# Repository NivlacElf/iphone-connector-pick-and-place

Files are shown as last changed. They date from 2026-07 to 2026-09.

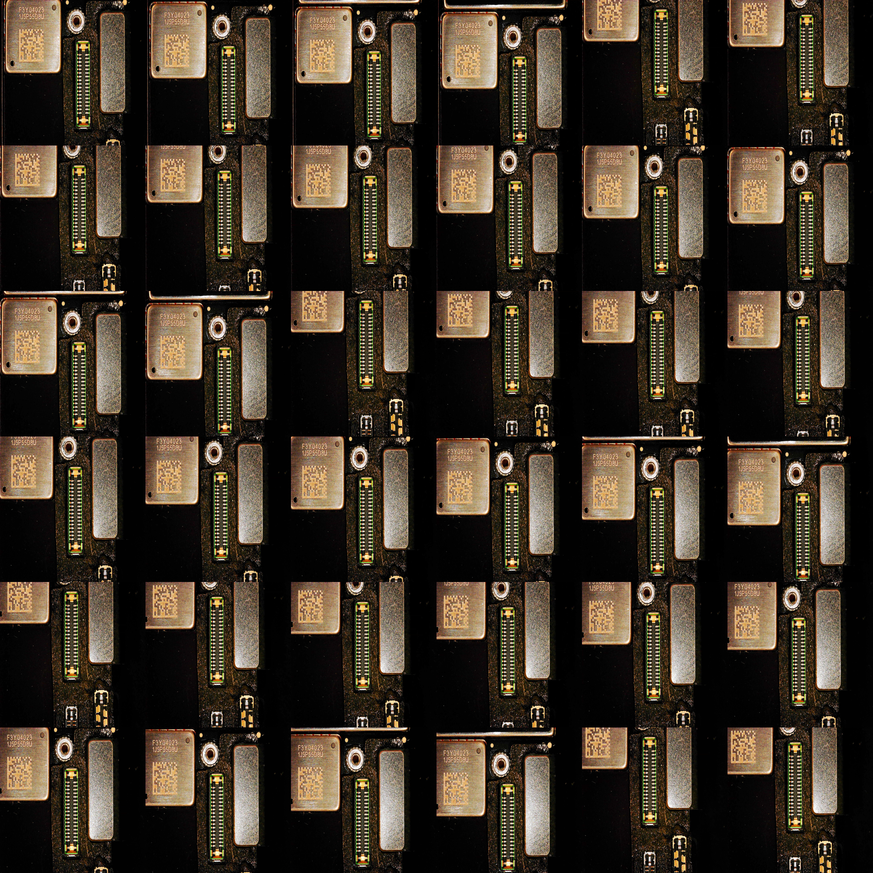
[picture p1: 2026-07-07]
experiments/Socket Sam/grid/socket_grid_6x6.png

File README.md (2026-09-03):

# Autonomous iPhone Connector Pick-and-Place

A machine that picks up an Apple iPhone flex-cable plug and inserts it into its board socket. It's built from a modified Ender 3 3D printer, two cameras, and three custom-trained YOLOv8 vision models.

Connector mating is one of the last steps in phone assembly still done by human hands: the plug is a few millimeters wide and the socket tolerance is fractions of a millimeter. This project closes that gap with visual servoing instead of expensive precision robotics.

<!-- IMAGE: hero shot of the full rig (Ender 3 + toolhead + phone case holder), ~1200px wide -->
Full rig

**[▶ Watch the full demo video](YOUTUBE_LINK_HERE)**

## How It Works

The Ender 3 is used as a cheap, precise 3-axis CNC motion platform, driven over USB with G-code. Two cameras give the machine eyes:

| Camera | Direction | Job |
|---|---|---|
| Toolhead camera | Looking down | Finds the plug on the table, then finds the socket on the phone |
| Microscope | Looking up | Inspects the plug held by the picker to measure its exact offset and angle |

Three YOLOv8 oriented-bounding-box models handle detection: `plug_front.pt` (plug on the table), `plug_back.pt` (pin side of the plug, viewed from below), and `SocketML.pt` (board socket). (see google drive models foulder for the models. The file is too big for github)

Each process uses the same pattern: detect the target, convert its pixel offset from image center to millimeters (calibrated per Z height), move the printer, and re-detect — repeating until the error converges to near zero.

### The Pipeline

<!-- IMAGE: 4-panel strip showing phases 1, 3, 4, 5 (annotated camera views), or one diagram -->
Pipeline phases

1. **Find the plug** — the downward camera servos over the plug, then applies the calibrated camera-to-picker offset so the picker lands exactly on the grab point.
2. **Pick up** — the toolhead descends and the pneumatic vacuum gripper grabs the plug.
3. **Square the plug** — the plug is pressed against a straight edge to zero out its rotation.
4. **Inspect from below** — the machine holds the plug over the upward microscope, verifies the squaring worked (angle check), and measures precisely where the plug sits on the picker. This shift is carried into the final math, so a slightly off-center grab still ends in a perfect insertion.
5. **Find the socket** — the downward camera servos over the board socket on the phone.
6. **Insert** — the true target is computed as `socket position + nominal offset − measured grab shift`, and a slow stepped descent seats the plug into the socket.

## Hardware

<!-- IMAGE: close-up of the custom toolhead attachment + picker -->
Toolhead and picker

<!-- IMAGE: phone case holder with iPhone board in place -->
Phone holder

- Creality Ender 3 3D printer (motion platform, stock firmware, G-code over serial)
- [Pneumatic vacuum gripper for electronics (McMaster-Carr 5083N126)](https://www.mcmaster.com/5083N126/) to pick up the plug
- Custom 3D-printed toolhead camera/gripper mount
- Custom 3D-printed camera base mount
- Custom 3D-printed iPhone holder to fixture the phone
- Downward-facing toolhead camera (1600×1200)
- Upward-facing USB microscope
- Straight-edge fixture for squaring the plug

All custom parts were designed in CAD — STEP files are in [`cad/`](cad/), ready to print.

## Machine Learning

The three models were trained on images captured by the machine itself: a grid-sweep script (`training/Picture_Grid.py`) moves the camera over the workspace and photographs the target at known coordinates, giving hundreds of labeled-position images per session. Labels were drawn as oriented rectangles/parallelograms, propagated across the sweep, and converted from CSV to YOLO OBB format (`scripts/csvToYolo.py`, `scripts/yolo_to_obb.py`).

<!-- IMAGE: example detection — camera frame with OBB drawn on the plug or socket -->
YOLO detection example

Oriented bounding boxes (rather than axis-aligned ones) matter here: the plug's rotation is part of the measurement, and the OBB angle feeds directly into the squaring verification.

## Repository Structure

```
├── src/                  # Final pipeline
│   ├── alignment.py      #   Full pick-and-place workflow (run this)
│   ├── Calibrate.py      #   Offset calibration helpers
│   ├── CenterPin.py, CenterSocket.py, goTo.py, debug tools
│   └── models/           #   Trained YOLOv8 weights (not in git — see Models below)
├── cad/                  # STEP files for the 3D-printed mounts and iPhone holder
├── calibration/          # Camera px→mm, pin, and table calibration scripts
├── training/             # Dataset capture (grid sweeps), labeling, earlier training iterations
├── scripts/              # Shared utilities (CSV→YOLO conversion, camera capture, jogging)
├── experiments/          # Earlier standalone experiments (pin centering, socket finding, ...)
└── docs/media/           # Photos and demo media
```

## Running It

Requires Python 3, an Ender 3 on a USB serial port, and both cameras connected.

```bash
pip install ultralytics opencv-python py3DCal

cd src
python alignment.py
```

Before a first run on new hardware, the camera-to-picker offsets and px→mm ratios in the configuration block at the top of `alignment.py` need to be recalibrated using the scripts in `calibration/`.

### Models

The trained weights (`plug_front.pt`, `plug_back.pt`, `SocketML.pt`) are excluded from git due to size. <!-- TODO: add a download link (GitHub Release is the easiest option) -->

## Results

<!-- IMAGE: the money shot — plug seated in the socket, close-up -->
Successful insertion

The machine repeatably locates the plug, measures its grab error to sub-millimeter precision on the upward microscope, and seats it into the board socket. See the [demo video](YOUTUBE_LINK_HERE) for a full end-to-end run.

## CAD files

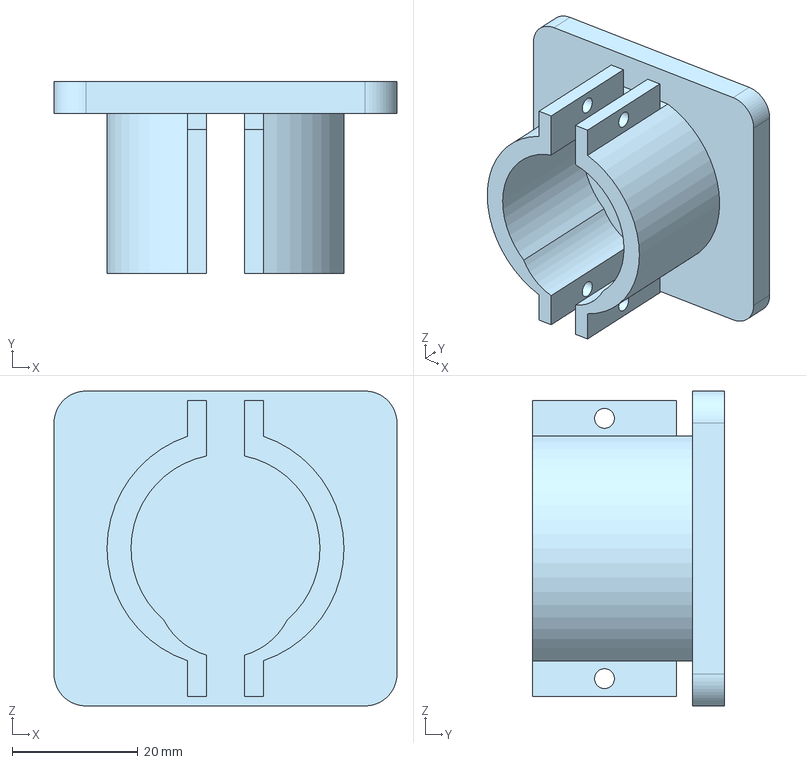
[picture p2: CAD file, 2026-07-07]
cad/Camera Base Mount.step
54.5 x 30.5 x 50.0 mm

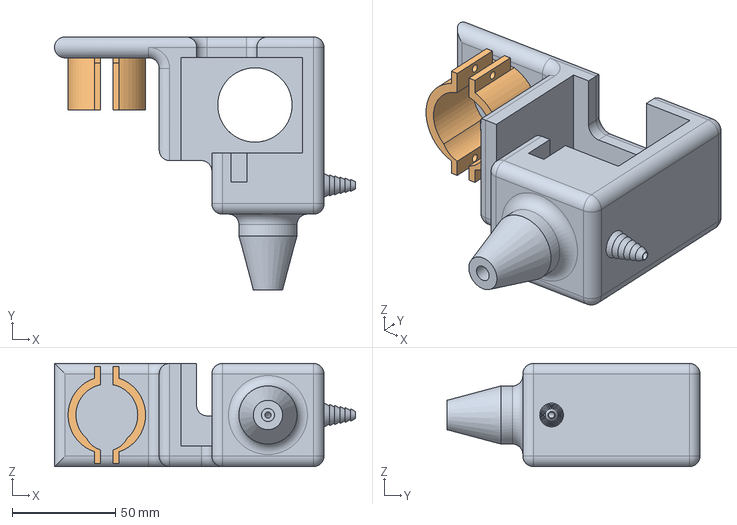
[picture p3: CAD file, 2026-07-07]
cad/Camera Printhead Mount v5.step
146.0 x 122.8 x 50.0 mm

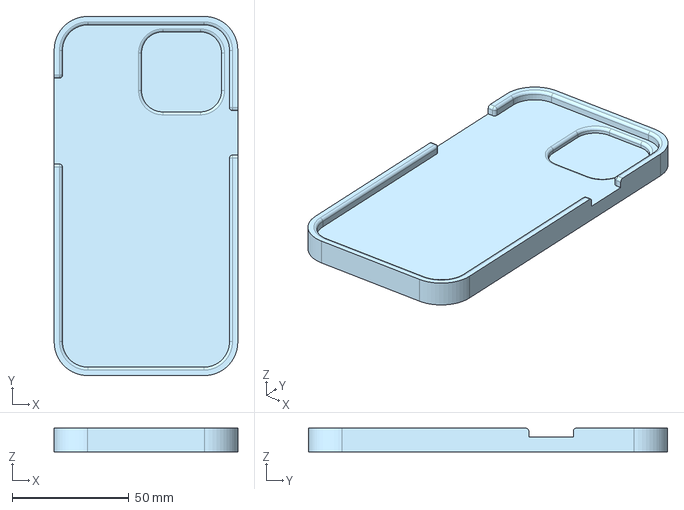
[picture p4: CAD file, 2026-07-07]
cad/iPhone Holder V2.step
78.7 x 153.9 x 10.2 mm

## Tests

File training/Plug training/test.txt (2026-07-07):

0 0.635625 0.415000 0.758125 0.328333 0.953750 0.820000 0.831250 0.906667
0 0.633125 0.416667 0.748750 0.330000 0.993750 0.910833 0.878125 0.997500
0 0.627500 0.414167 0.753750 0.325000 0.975625 0.884167 0.849375 0.973333
0 0.630000 0.413333 0.750000 0.326667 0.981875 0.897500 0.861875 0.984167
0 0.631875 0.415833 0.748750 0.330000 0.983750 0.899167 0.866875 0.985000
0 0.003750 0.169167 0.115000 0.083333 0.358750 0.645833 0.247500 0.731667
0 0.601250 0.429167 0.713125 0.323333 0.995000 0.853333 0.883125 0.959167
0 0.831875 0.266667 0.940625 0.383333 0.635000 0.889167 0.526250 0.772500
0 0.416875 0.586667 0.291250 0.693333 0.029375 0.145000 0.155000 0.038333
0 0.521250 0.921667 0.478125 0.750000 0.940000 0.543333 0.983125 0.715000
0 0.618125 0.410833 0.736250 0.317500 0.984375 0.876667 0.866250 0.970000
0 0.618125 0.402500 0.733750 0.310833 0.982500 0.869167 0.866875 0.960833
0 0.618125 0.407500 0.735000 0.315833 0.981875 0.875833 0.865000 0.967500
0 0.436250 0.375000 0.524375 0.525000 0.140000 0.925000 0.051875 0.775000
0 0.066250 0.170833 0.165625 0.043333 0.503125 0.511667 0.403750 0.639167
0 0.186875 0.537500 0.321250 0.529167 0.343750 1.178333 0.209375 1.186667
0 0.066875 0.170833 0.166875 0.042500 0.504375 0.510000 0.404375 0.638333
0 0.150000 0.605833 0.063750 0.455000 0.451250 0.060833 0.537500 0.211667
0 0.973750 0.881667 0.848750 0.978333 0.603750 0.415833 0.728750 0.319167
0 0.893750 0.424167 0.976250 0.564167 0.592500 0.965000 0.510000 0.825000
0 0.569375 0.951667 0.485000 0.802500 0.871250 0.413333 0.955625 0.562500

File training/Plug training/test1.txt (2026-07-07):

0 0.893750 0.418333 0.980000 0.567500 0.593750 0.964167 0.507500 0.815000
0 0.893125 0.421667 0.976875 0.561667 0.595625 0.966667 0.511875 0.826667
0 0.893750 0.420000 0.980000 0.565833 0.599375 0.965000 0.513125 0.819167
0 0.894375 0.425000 0.976875 0.566667 0.593750 0.962500 0.511250 0.820833
0 0.970625 0.889167 0.850625 0.978333 0.614375 0.414167 0.734375 0.325000
0 0.968750 0.885000 0.856250 0.974167 0.608125 0.418333 0.720625 0.329167
0 0.970000 0.880833 0.853750 0.971667 0.608750 0.414167 0.725000 0.323333
0 0.968125 0.884167 0.848750 0.975833 0.606875 0.415833 0.726250 0.324167
0 0.517500 0.518333 0.618750 0.388333 0.954375 0.853333 0.853125 0.983333
0 0.520625 0.514167 0.617500 0.390000 0.953125 0.855000 0.856250 0.979167
0 0.520625 0.515833 0.618125 0.392500 0.951250 0.860833 0.853750 0.984167

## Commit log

2026-07-07 Baseline commit of Apple Connectors code
    [Socket_Coordinates.csv]
2026-07-07 Reorganize repo: src/, calibration/, training/, scripts/, experiments/, docs/
    [Socket_Coordinates.csv]
2026-07-07 Add CAD STEP files and pneumatic gripper to hardware docs
    [Camera Base Mount.step, Camera Printhead Mount v5.step, iPhone Holder V2.step]
2026-09-03 file changes
    [Socket_Coordinates.csv]
